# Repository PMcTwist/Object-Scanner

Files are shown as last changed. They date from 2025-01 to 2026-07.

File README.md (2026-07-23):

# Object Scanner

A low-cost, real-time 3D scanning platform built using **Python**, **C++**, **Arduino**, **Raspberry Pi**, and **LiDAR** technology.

Originally developed as a capstone project at the **University of Windsor**, Object Scanner was designed to demonstrate that accurate 3D scanning can be achieved using affordable, readily available hardware while providing a modular platform for future development and experimentation.

---

## Project Overview

Commercial 3D scanners are often prohibitively expensive for students, hobbyists, and small organizations. Object Scanner was created to provide an affordable alternative capable of producing real-time point cloud visualizations using open-source software and off-the-shelf hardware.

The system combines embedded firmware, desktop software, and custom hardware into a complete scanning platform capable of:

- Capturing real-time LiDAR/IR measurements
- Controlling dual-axis motion using stepper motors
- Processing scan data on a Raspberry Pi
- Visualizing point cloud data in real time
- Exporting captured scan information for future processing

---

## Features

- Real-time 3D point cloud visualization
- Python desktop application using PyQt5
- Arduino-based motion controller
- Raspberry Pi deployment
- SQLite scan data storage
- Live serial communication between hardware and software
- Configurable scan parameters
- Exportable scan data
- Modular architecture for future sensor upgrades

---

# Technologies

## Software

- Python
- PyQt5
- SQLite
- Matplotlib
- PySerial

## Embedded

- Arduino
- C++
- Stepper Motor Control
- Serial Communication

## Hardware

- Raspberry Pi
- TF-Luna LiDAR / IR Sensor
- NEMA Stepper Motors
- CNC Shield
- A4988 Drivers

---

# System Architecture

```
               +----------------------+
               |    Python GUI        |
               |      (PyQt5)         |
               +----------+-----------+
                          |
                    Serial Connection
                          |
               +----------v-----------+
               |      Arduino         |
               | Motion Controller    |
               +----------+-----------+
                          |
          +---------------+----------------+
          |                                |
   Stepper Motors                    LiDAR / IR Seonsor
          |                                |
          +---------------+----------------+
                          |
                    Scan Coordinates
                          |
               +----------v-----------+
               |    SQLite Database   |
               +----------+-----------+
                          |
               Real-Time 3D Visualization
```

---

# Screenshots

## User Interface

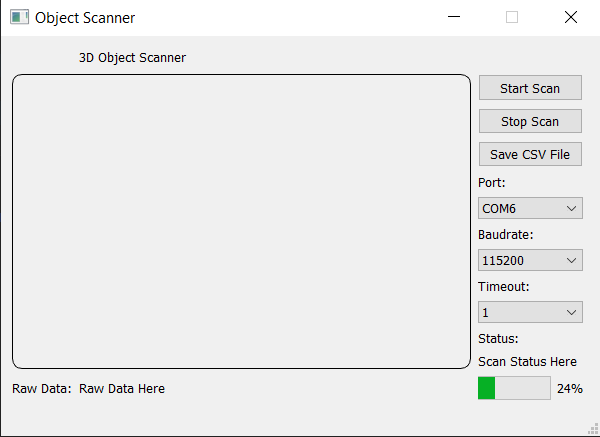
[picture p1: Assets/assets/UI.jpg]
Basic UI

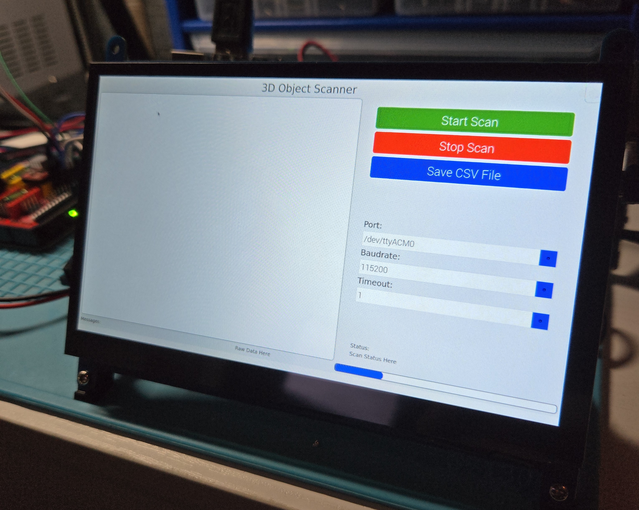
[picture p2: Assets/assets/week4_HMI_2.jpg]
UI Mock up


---

## Hardware

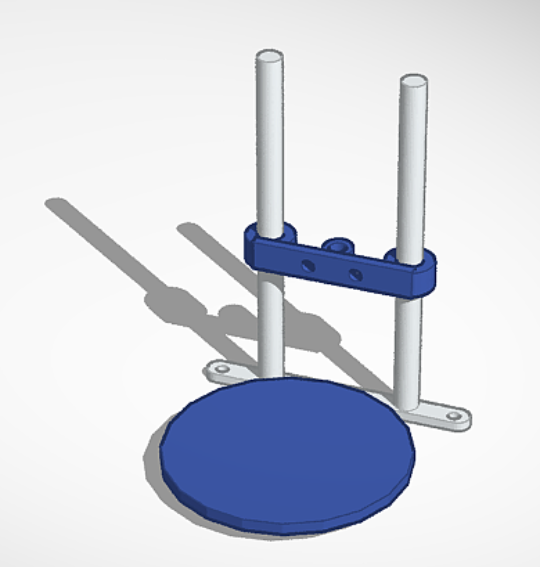
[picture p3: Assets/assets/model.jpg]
First CAD

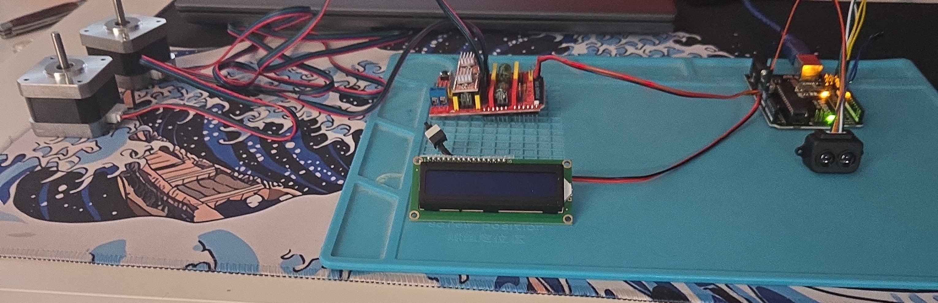
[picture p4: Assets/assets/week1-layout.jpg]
Basics

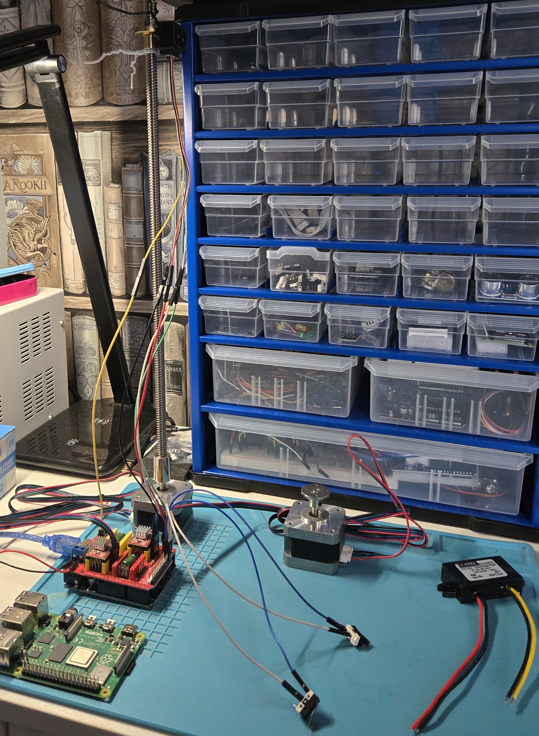
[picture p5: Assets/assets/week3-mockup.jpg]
Mechanical Mock up

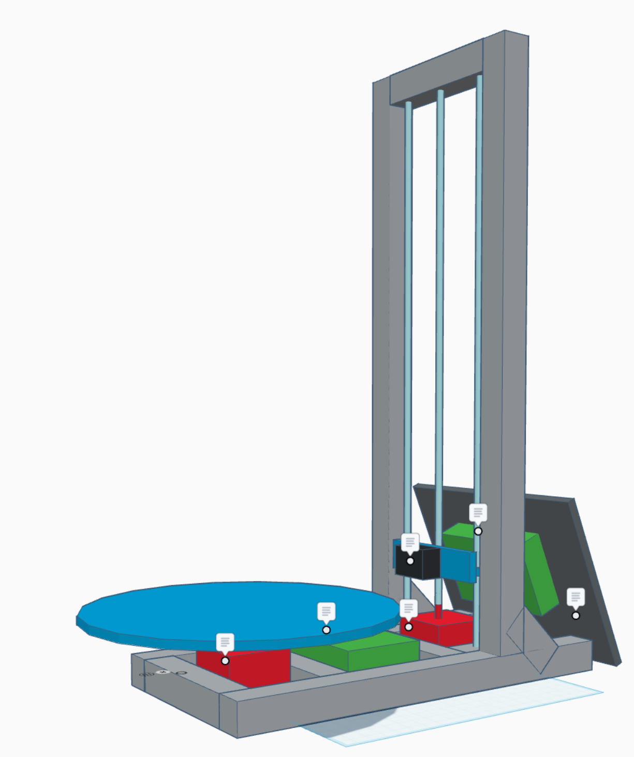
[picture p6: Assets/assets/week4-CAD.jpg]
CAD Update

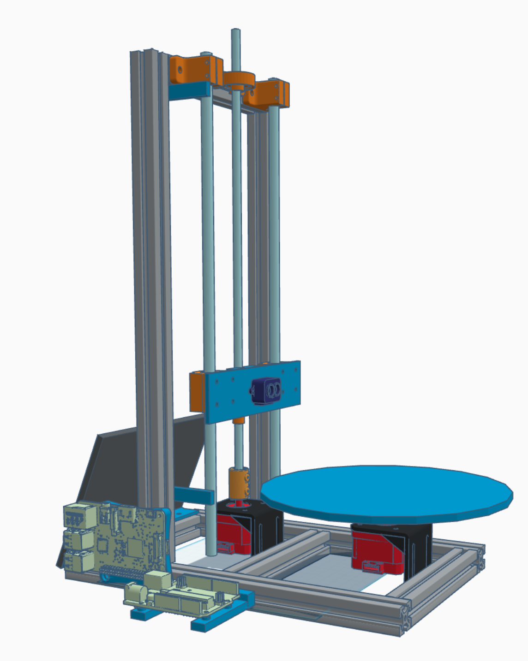
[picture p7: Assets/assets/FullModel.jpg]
Final Cad


---

## Run-Time

UI Update

---

# Repository Structure

```
Object-Scanner/

Arduino/
    Embedded firmware

Assets/
    Images and UI resources

Database/
    SQLite scan database

Models/
    3D printable components

Python/
    Desktop application

Releases/
    Executable releases

Scripts/
    Raspberry Pi startup scripts
```

---

# Installation

## Requirements

- Python 3.11+
- PyQt5
- Matplotlib
- PySerial
- SQLite3

Install dependencies:

```bash
pip install -r requirements.txt
```

---

# Running

Launch the application:

```bash
python scanner.py
```

Connect the Arduino via USB and configure the correct COM port before starting a scan.

---

# Future Improvements

Potential future enhancements include:

- Multi-threaded scan processing improvements
- Higher resolution scanning
- Additional sensor support
- Mesh generation
- STL export
- Network-based control
- Improved scan filtering algorithms

---

# Lessons Learned

This project provided valuable experience in:

- Embedded systems
- Python application development
- Hardware/software integration
- Real-time data visualization
- Multithreaded programming
- SQLite databases
- Raspberry Pi deployment
- Project planning
- Team collaboration

---

# Authors

## Patrick Maynard

Software Development  
Software Design • Embedded Systems • Automation

Email: patmaynard452@gmail.com
LinkedIn: https://www.linkedin.com/in/pat-maynard-b97a05b5/

---

## Kevin McClintock

Mechanical Design • Embedded Systems • Automation

Email:
LinkedIn:

---

# License

This project is released under the MIT License.

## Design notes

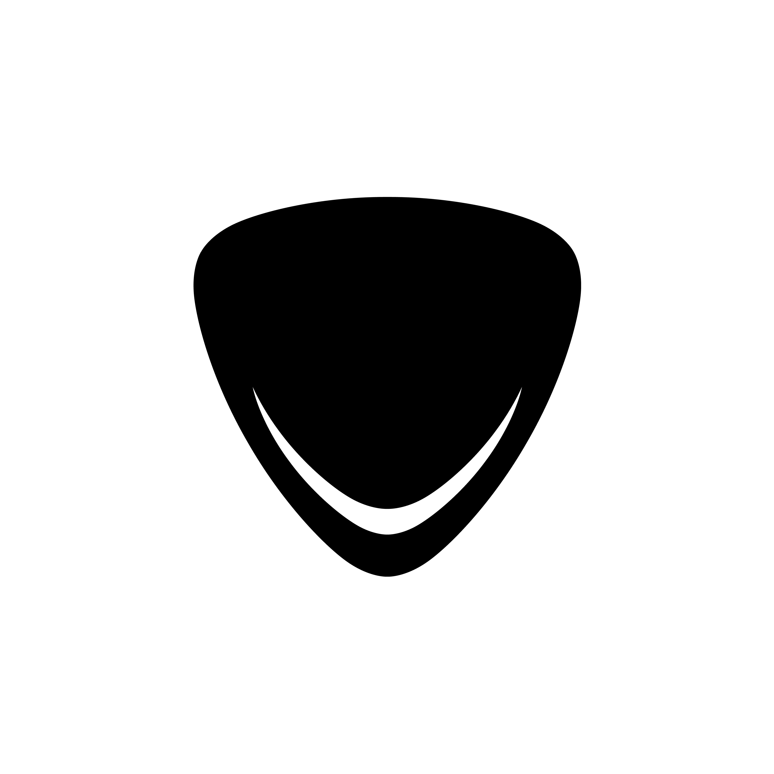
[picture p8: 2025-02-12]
Assets/arrow.png

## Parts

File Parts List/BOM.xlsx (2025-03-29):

Item | Cost | Link
CNC Driver Iinterface | 95 | RATTMMOTOR 3D Printer CNC Controller Kit Compatible with Arduino IDE, Nema17 Stepper Motor+UNO R3 Improvement Borad+CNC GRBL Shield Board V3 Expansion Board+DRV8825 Drivers+Mechanical Switches : Amazon.ca: Industrial & Scientific (https://www.amazon.ca/RATTMMOTOR-Controller-Compatible-Improvement-Mechanical/dp/B08KXL4GH7)
MERQC A4988 Driver
NEMA17 Motors
Arduino UNO
Motor Mounts
T8 8mm Threaded Rod | 17.9 | Richer-R 3D Printer Screw Rod, T8 8mm Trapezoidal Stainless Steel Threaded Rod Lead Screw & Brass Nut Easy to Install and Convenient to Use, No Need to Process for 3D Printer(100mm) : Amazon.ca: Industrial & Scientific (https://www.amazon.ca/Richer-R-Trapezoidal-Stainless-Threaded-Convenient/dp/B07CM3XTLX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)
8mm Guide Bearings | 11.99 | Eowpower 4 Pieces 8 mm Bore Diameter Ball Mounted Pillow Block Insert Bearings : Amazon.ca: Industrial & Scientific (https://www.amazon.ca/Eowpower-Diameter-Mounted-Pillow-Bearing/dp/B01MT1MODX)
8mmx400mm Guide Rods | 13.99 | Linear Motion Rods 2PCS 8mmx 250mm (0.315 x 9.84inches) Case Hardened Chrome Plated Linear Motion Rod Shaft Guide for 3D Printer, DIY, CNC - Metric h8 Tolerance : Amazon.ca: Industrial & Scientific (https://www.amazon.ca/Linear-Motion-9-84inches-Hardened-Printer/dp/B08JGD9F5P)
5mm Bore Flange Coupling | 13.99 | 4Pcs 8mm Flange Coupling Connector, Rigid Guide Model Coupler Accessory, Shaft Axis Fittings for DIY RC Model Motors : Amazon.ca: Tools & Home Improvement (https://www.amazon.ca/Coupling-Connector-Coupler-Accessory-Fittings/dp/B08334MFVT)
Threaded Rod Coupler | 16.49 | https://www.amazon.ca/uxcell-Coupling-Stainless-Connector-Accessories/dp/B07P82D36N
Power Adapter | 20 | Facmogu 3 Prong 12V 5A 60W AC to DC Power Supply Adapter with 9.84ft / 3m LONG CABLE, 5.5x2.1mm & 2.5mm Plug, AC 100-240V to DC 12V Switching Transformer Converter for CCTV Camera LED Strip LCD Screen : Amazon.ca: Electronics (https://www.amazon.ca/dp/B09BQBWKKT?ref=ppx_yo2ov_dt_b_fed_asin_title&th=1)
12V to 5V step down | 10.05 | https://www.amazon.ca/GAVIK-Waterproof-Buck-Converter-Intelligent/dp/B0CN455Z84
RaspBerry PI 4 | 101 | https://www.bestbuy.ca/en-ca/product/raspberry-pi-4-model-b-2019-quad-core-64-bit-wifi-bluetooth/15322892
RaspPi 7" HMI Screen | 55.36 | 7 Inch LCD Touch Screen, 1024x600 IPS Display with Stand, HDMI Portable Monitor for Raspberry Pi 5/4B/3B+/3B/B+/Zero/400, BB Black, Windows 10 8 7, Free Driver : Amazon.ca: Electronics (https://www.amazon.ca/1024x600-Display-Portable-Monitor-Raspberry/dp/B0CRRB1GFN)
Frame Extrusion | 60 | SeekLiny 10PCS T Slot 2020 Aluminum Extrusion European Standard 250mm(9.8’’) Length Anodized Extruded Aluminum for CNC DIY 3D Printer and Industrial Bracket Making, Ropes - Amazon Canada (https://www.amazon.ca/SeekLiny-Aluminum-Extrusion-European-Industrial/dp/B0CN6MFYJJ)
TF-Luna LiDAR Sensor | 36.59 | Wishiot TF-Luna LiDAR Range Finder Sensor 0.2m-8m Single-Point Ranging Module UART/I2C 5V with 6Pin Terminal to Dupont Cable for Arduino/RPi Pico/Pixhawk/WiFi_Lora_32 : Amazon.ca: Electronics (https://www.amazon.ca/Wishiot-TF-Luna-Single-Point-Terminal-WiFi_Lora_32/dp/B09PZ559ZB)
Total: | 452.36
*Note Frame can be 3D Printed from Included STL files

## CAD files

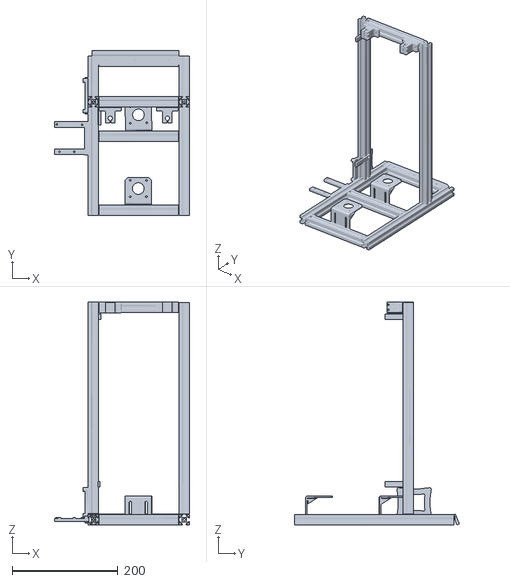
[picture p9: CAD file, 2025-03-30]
Models/PrintedParts/Full-Frame.stl
255.6 x 312.1 x 422.0

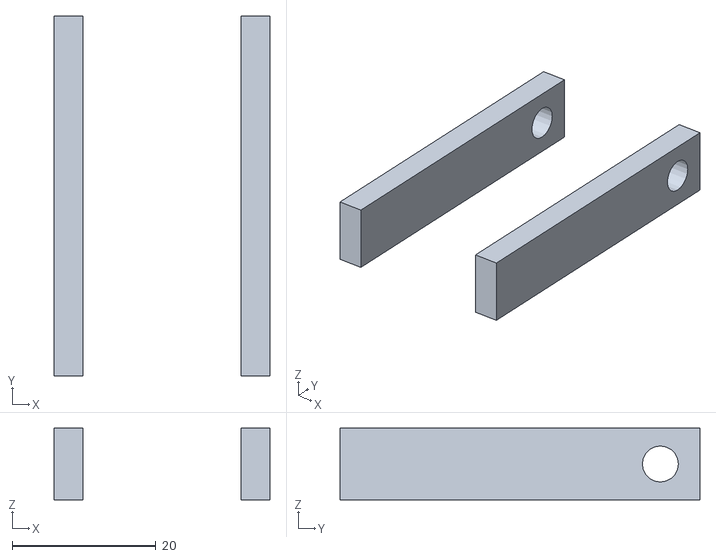
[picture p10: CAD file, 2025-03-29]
Models/PrintedParts/limit_mounts.stl
30.0 x 50.0 x 10.0

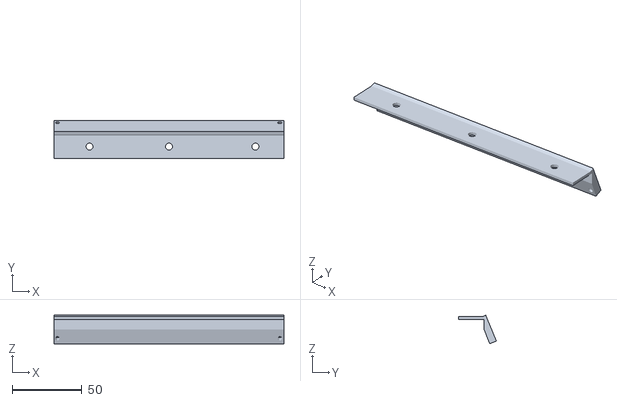
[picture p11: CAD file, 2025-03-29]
Models/PrintedParts/Screen Mount.stl
165.0 x 27.1 x 20.5

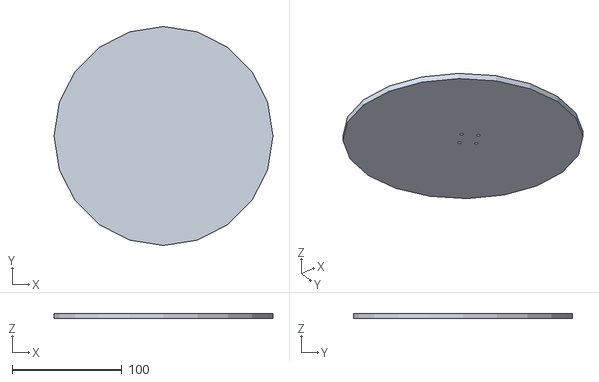
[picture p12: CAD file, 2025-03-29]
Models/PrintedParts/Platform.stl
200.0 x 200.0 x 5.00

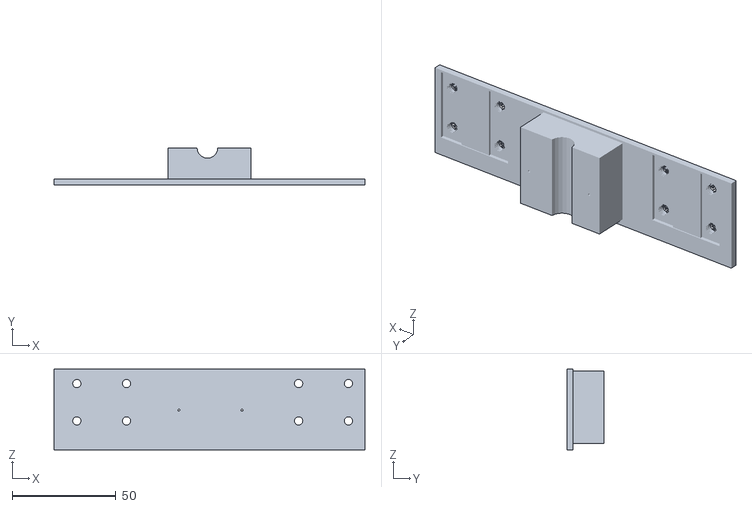
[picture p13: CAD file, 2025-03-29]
Models/PrintedParts/Sensor-Plate.stl
150.0 x 18.0 x 39.0

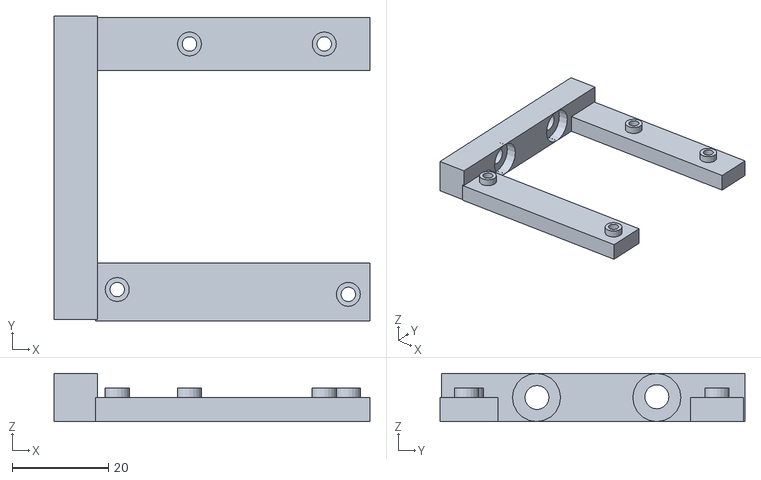
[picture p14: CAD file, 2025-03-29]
Models/PrintedParts/uno_Mount.stl
65.6 x 63.3 x 10.0

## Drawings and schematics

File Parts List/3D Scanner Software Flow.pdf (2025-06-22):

# Python HMI - Raspberry Pi or USB PC

# 3D Scanner Program Flow Diagram

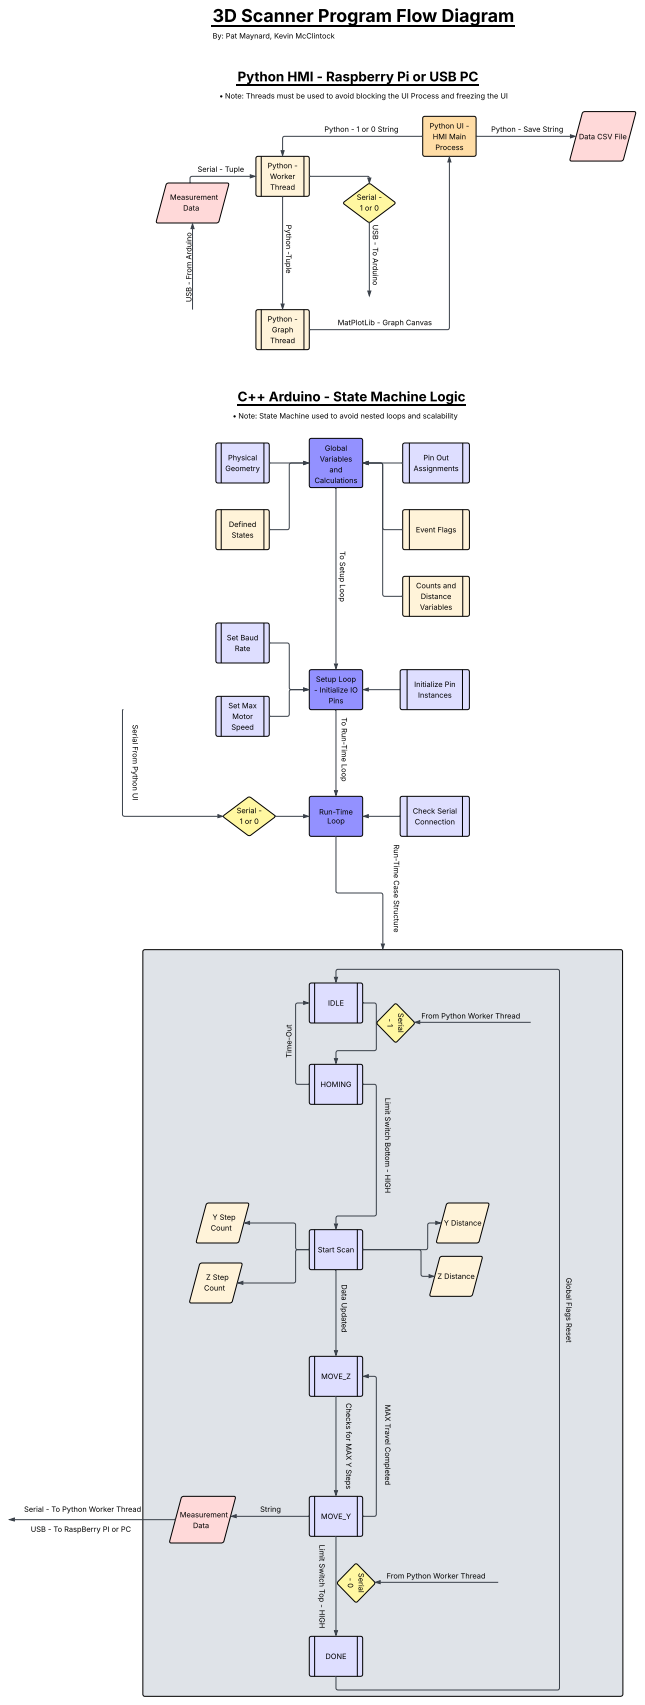
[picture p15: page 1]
Python UI - HMI Main Process; Python - Worker; Thread; Python - Graph Thread; Measurement Data; Serial - Tuple; Python - 1or 0 String; Serial - 1or 0; Global Variables and Calculations; Setup Loop - Initialize IO Pins; Physical Geometry; Pin Out Assignments; Defined States; Event Flags; Counts and Distance Variables; Check Serial Connection; Set Baud Rate; Initialize Pin Instances; Set Max Motor Speed; Run-Time Loop; IDLE; HOMING; Tim; e-Out; Start Scan; Y Step Count; Z Step Count; Y Distance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

By: Pat Maynard, Kevin McClintock

- Note: Threads must be used to avoid blocking the UI Process and freezing the UI

Python - Save String

Data CSV File

MatPlotLib - Graph Canvas

C++ Arduino - State Machine Logic

- Note: State Machine used to avoid nested loops and scalability

From Python Worker Thread

Serial - To Python Worker Thread

USB - To RaspBerry PI or PC

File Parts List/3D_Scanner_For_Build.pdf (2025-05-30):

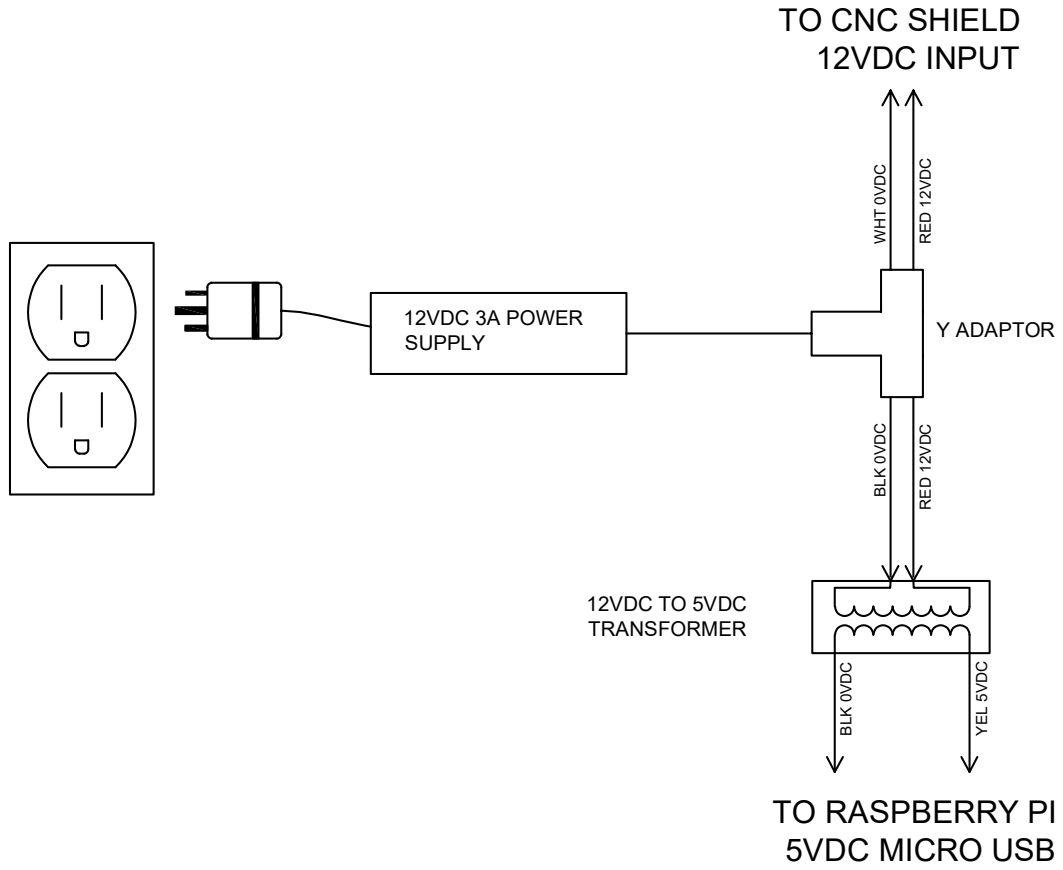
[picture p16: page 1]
12VDC 3A POWER; SUPPLY; Y ADAPTOR; 5VDC MICRO USB WHT 0VDC; RED ¹²VDC BLK ⁰VDC; YEL 5VDC; 12VDC TO 5VDC TRANSFORMER

TO CNC SHIELD
12VDC INPUT

TO RASPBERRY PI

# LIDAR SENSOR

# TF-LUNA

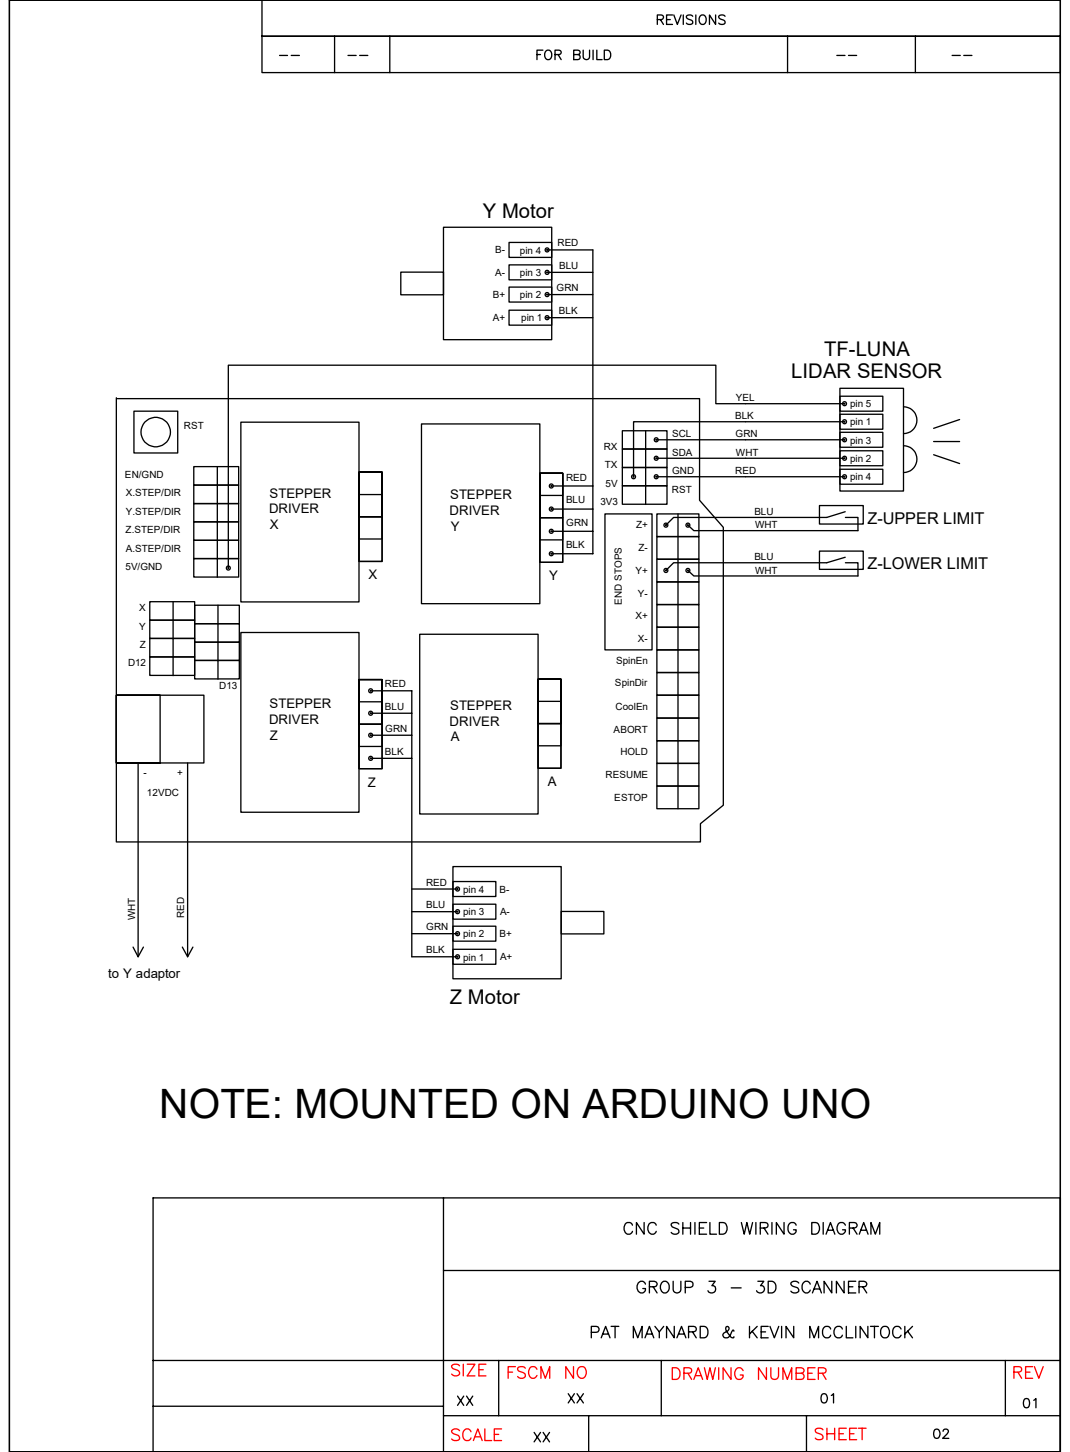
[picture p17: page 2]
X.STEP/DIR; Y.STEP/DIR; Z.STEP/DIR; A.STEP/DIR; 5V/GND; EN/GND; 12VDC; SCL RX; SDA GND; RST; Z+Z- Y+Y- X+X- SpinEn; RESUME; STEPPER DRIVER X; STEPPER DRIVER Z; STEPPER DRIVER Y; STEPPER DRIVER A; to Y adaptor; Z Motor WHT; RED; Z-UPPER LIMIT; Z-LOWER LIMIT; pin 5; pin 1; pin 3; pin 2; pin 4; BLU GRN; BLK; Y Motor RED; pin 3 B-; pin 4 A- B+A+

YELBLU WHT BLU WHT
BLK GRN WHT RED

ESTOP END STOPS X

SpinDir CoolEn ABORT HOLD

NOTE: MOUNTED ON ARDUINO UNO

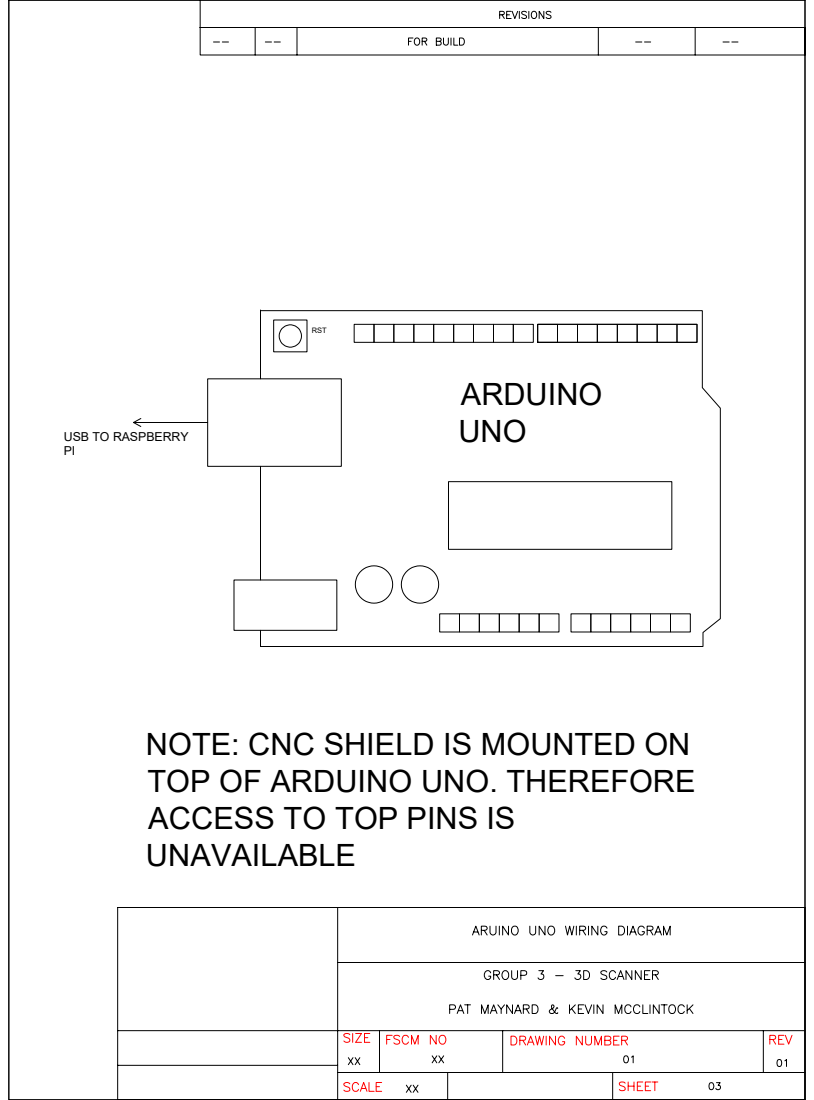
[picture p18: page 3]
RST; ARDUINO; UNO

USB TO RASPBERRY

NOTE: CNC SHIELD IS MOUNTED ON
TOP OF ARDUINO UNO. THEREFORE
ACCESS TO TOP PINS IS
UNAVAILABLE

# 7" HMI HDMI CABLE

# USB CABLE (TOUCH AND POWER)

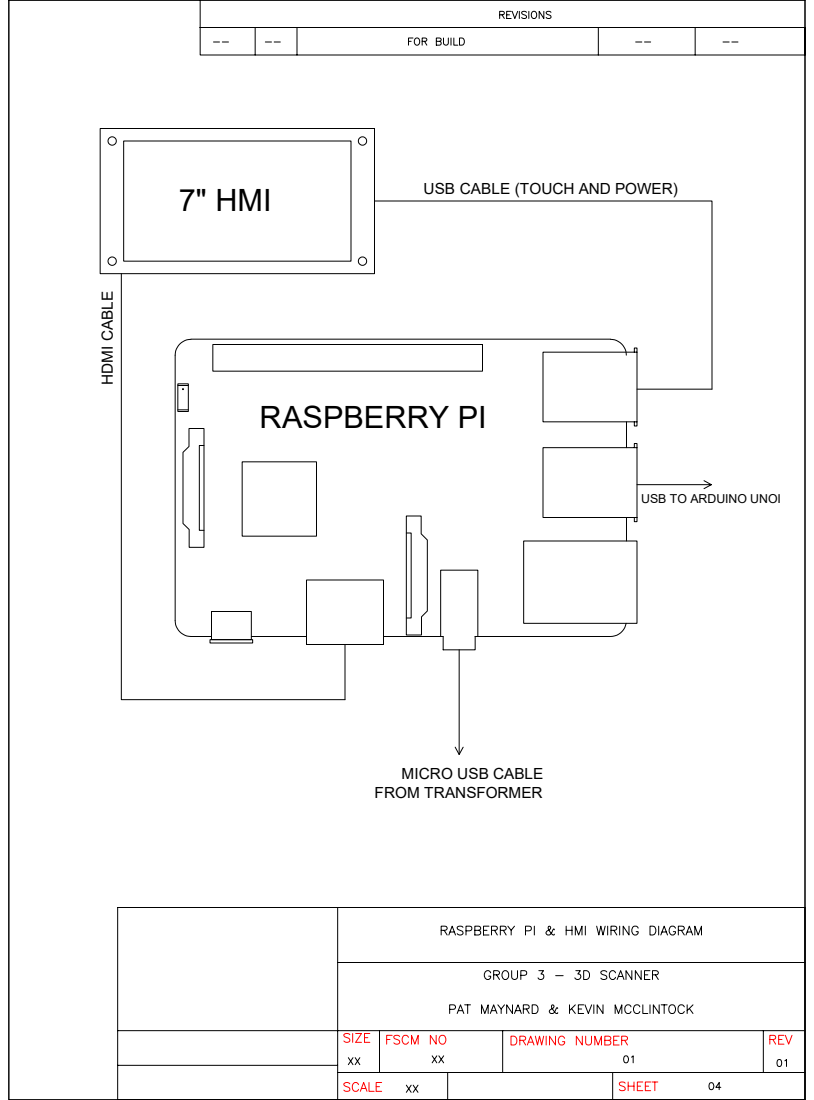
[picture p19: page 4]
RASPBERRY PI

USB TO ARDUINO UNOI

MICRO USB CABLE
FROM TRANSFORMER

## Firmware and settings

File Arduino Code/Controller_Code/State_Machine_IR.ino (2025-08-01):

#include <Arduino.h>

// ===== Sharp IR Sensor =====
#define SENSOR_PIN A0
int scan_amount = 40;  // Number of readings to average

// distance of sensor from middle of platform
const float distance_to_center = 150.0; // mm - adjust this to your actual setup

// ==== Full Step Configuration =====
const int micro_jumper = 2; // 2 is for 1/2 microstepping

// ===== Scan Parameters =====
// Reduce the scans per step to help scan time
const int stepsPerReading = 1;  // Take a reading every single step - no more multiple steps!

// ===== Platform Geometry =====
const float y_StepAngle = 1.8; // degrees per full step
const int motor_steps_per_rev = 360 / y_StepAngle; // 200 for 1.8°
const int stepsPerRev = motor_steps_per_rev * micro_jumper; // 200 * 2 = 400 for 1/2 steps
const float platformRadius = 100; // mm
const float platformCircumference = 2.0 * 3.1415926535 * platformRadius;
const float y_DistancePerStep = platformCircumference / stepsPerRev;

// ===== Threaded Rod Geometry =====
const float rodPitch = 2; // mm
const float z_stepsPerRev = 200 * micro_jumper; // 200 steps/rev for NEMA 17
const float z_DistancePerStep = rodPitch / z_stepsPerRev;

// ===== Stepper Pins & Setup =====
#define ENABLE_PIN 8

#define Y_STEP_PIN 3
#define Y_DIR_PIN 6

#define Z_STEP_PIN 4
#define Z_DIR_PIN 7
 
#define limitSwitchTop 11
#define limitSwitchBot 10

// ===== Scan State Machine =====
enum ScanState {
  IDLE,
  HOMING,
  START_SCAN,
  MOVE_Z,
  MOVE_Y,
  RECORD_DATA,
  DONE
};
ScanState scanState = IDLE;

// ===== Motion & Scan Variables =====
// Status flags
bool homingComplete = false;
bool running = false;
bool stopFlag = true;
bool homingStarted = false;
bool foundValidPoint = false;

// data send timer
unsigned long lastDataSendTimer = 0;
const unsigned long dataSendInterval = 50; // Reduced from 100ms to 50ms

// Homing variables
unsigned long homingStartTime = 0;
const unsigned long homingTimeout = 1000000000;

// 3 measured distances
float x_dist = 0.0;
float y_axis_total_distance = 0.0;
float z_axis_total_distance = 0.0;

// Array of send data
float dataArray[3];

int yStepCount = 0;
int zStepCount = 0;

const int yStepsPerZ = stepsPerRev; 
const int zStepsTotal = 200 * micro_jumper;
 
// Step timing variables
unsigned long lastHomingStepTime = 0;
const unsigned long homingStepInterval = 800; // Reduced from 1000 to 800 microseconds
 
// Faster 1/2 microstepping reliable stepping functions
void stepY(int direction) {
  // Set direction and wait
  digitalWrite(Y_DIR_PIN, direction > 0 ? HIGH : LOW);
  delayMicroseconds(500); // Reduced from 2ms to 500µs
  
  // Create step pulse
  digitalWrite(Y_STEP_PIN, HIGH);
  delayMicroseconds(200); // Reduced from 300µs to 200µs
  digitalWrite(Y_STEP_PIN, LOW);
  
  // Delay between steps - significantly reduced for speed
  delay(50); // Reduced from 100ms to 50ms
}
 
void stepZ(int direction) {
  digitalWrite(Z_DIR_PIN, direction > 0 ? HIGH : LOW);
  delayMicroseconds(300); // Reduced from 500µs
  digitalWrite(Z_STEP_PIN, HIGH);
  delayMicroseconds(80); // Reduced from 100µs
  digitalWrite(Z_STEP_PIN, LOW);
  delay(3); // Reduced from 5ms to 3ms
}
 
void stepZHoming() {
  // Non-blocking homing step
  if (micros() - lastHomingStepTime >= homingStepInterval) {
    digitalWrite(Z_DIR_PIN, LOW); // Move down for homing
    digitalWrite(Z_STEP_PIN, HIGH);
    delayMicroseconds(10);
    digitalWrite(Z_STEP_PIN, LOW);
    lastHomingStepTime = micros();
  }
}

// Sharp IR sensor reading function (returns distance in cm)
float readSensor(int samples = 40) {
  float analog_total = 0;
  float measured_analog = 0;

  for (int i = 0; i < samples; i++) {
    measured_analog = analogRead(SENSOR_PIN);
    analog_total += measured_analog;
    delay(2);  // Small delay between readings
  }

  float distance = analog_total / samples;  // Get the mean
  
  // Convert analog reading to voltage (assuming 5V reference)
  distance = (distance * 5.0) / 1023.0;
  
  // Sharp GP2Y0A51SK0F formula from datasheet (distance in cm)
  distance = -5.40274*pow(distance,3) + 28.4823*pow(distance,2) - 49.7115*distance + 31.3444;
  
  return distance;  // Return distance in cm
}

// Helper function for float mapping
float mapFloat(float fval, float val_in_min, float val_in_max, float val_out_min, float val_out_max) {
  return (fval - val_in_min) * (val_out_max - val_out_min) / (val_in_max - val_in_min) + val_out_min;
}
 
// Setup loop to define parameters
void setup() {
  Serial.begin(115200);
  
  pinMode(SENSOR_PIN, INPUT);
  analogReference(DEFAULT);  // Use 5V reference for Sharp sensor
  
  pinMode(ENABLE_PIN, OUTPUT);
  digitalWrite(ENABLE_PIN, HIGH); // Enable steppers
  
  pinMode(Y_STEP_PIN, OUTPUT);
  pinMode(Y_DIR_PIN, OUTPUT);
  
  pinMode(Z_STEP_PIN, OUTPUT);
  pinMode(Z_DIR_PIN, OUTPUT);
 
  pinMode(limitSwitchBot, INPUT_PULLUP);
  pinMode(limitSwitchTop, INPUT_PULLUP);
  
  Serial.println("STAT(Ready with Sharp IR sensor!)");
}

// ===== Main Loop =====
// This loop runs the state machine for the scanning process
void loop() {
  // Event Listener for UI
  if (Serial.available() > 0) {
    char inputChar = Serial.read() & 0x7F;
    Serial.print("Received: ");
    Serial.println(inputChar);
   
    if (inputChar == '1') {
      if (!running) {
        Serial.println("STAT(Starting Scan)");
        scanState = HOMING;
        running = true;
        stopFlag = false;
      }
    } else if (inputChar == '0') {
      if (running) {
        Serial.println("STAT(Stopping Scan)");
        scanState = DONE;
      }
    }
  }
  
  // State Machine Case Structure
  switch (scanState) {
    // Wait for instructions
    case IDLE:
      break;
    
    // Homes the Z axis to the 0 point to start
    case HOMING:
      digitalWrite(ENABLE_PIN, LOW); // Enable steppers for homing
      if (!homingStarted) {
        Serial.println("STAT(Homing Z Axis...)");
        homingStartTime = millis();
        homingStarted = true;
        lastHomingStepTime = 0;
      }
      // Check if limit switch is still open (not triggered)
      if (digitalRead(limitSwitchBot) == HIGH) {
        // Take homing steps
        stepZHoming();
        // Check for timeout
        if (millis() - homingStartTime > homingTimeout) {
          Serial.println("STAT(Homing timeout: switch not triggered.)");
          homingComplete = false;
          running = false;
          stopFlag = true;
          homingStarted = false;
          scanState = IDLE;
        }
      } else {
        // Limit switch triggered - homing complete
        Serial.println("STAT(Z axis homed successfully.)");
        homingComplete = true;
        homingStarted = false;
        scanState = START_SCAN;
      }
      break;
    
    // Initialize scan parameters
    case START_SCAN:
      Serial.println("STAT(Scanning...)");
      yStepCount = 0;
      zStepCount = 0;
      y_axis_total_distance = 0;
      z_axis_total_distance = 0;
      scanState = MOVE_Y;
      break;

    // Move Y motor for platform rotation and take measurements
    case MOVE_Y:
      if (yStepCount < yStepsPerZ) {
        Serial.println("STAT(Scanning...)");

        // Calculate current angle BEFORE taking measurement (this is the current position)
        float angle = (yStepCount * 2.0 * PI) / stepsPerRev;

        // reset point flag
        foundValidPoint = false;

        // Take averaged Sharp IR measurement (in cm)
        x_dist = readSensor(40);

        // Convert distance to mm and apply the working formula from reference code
        float measured_distance_mm = x_dist * 10; // Convert cm to mm
        float distance_from_center = distance_to_center - measured_distance_mm;

        // Check if the measurement is valid (object is between sensor and center)
        if (distance_from_center > 0 && distance_from_center <= (platformRadius * 2)) {
          // Scanned point is valid
          foundValidPoint = true;

          // Calculate Cartesian coordinates using the working formula
          float x = sin(angle) * distance_from_center;  // Note: sin for X
          float y = cos(angle) * distance_from_center;  // Note: cos for Y
          float z = z_axis_total_distance;

          // Prepare data
          dataArray[0] = x;
          dataArray[1] = y;
          dataArray[2] = z;

          // Send data with throttled timing applied (now faster)
          if (millis() - lastDataSendTimer >= dataSendInterval) {
            String dataToSend = String("DATA(") + String(dataArray[0]) + "," + String(dataArray[1]) + "," + String(dataArray[2]) + String(")");
            Serial.println(dataToSend);
            lastDataSendTimer = millis();
          }
        }

        // NOW move to next position AFTER taking the measurement
        for (int i = 0; i < stepsPerReading; i++) {
            stepY(1);
            y_axis_total_distance += y_DistancePerStep;
            yStepCount++;
            
            // Check if we've reached the total steps
            if (yStepCount >= yStepsPerZ) {
                break;
            }
        }
        
        // Faster delay between measurements
        delay(100); // Reduced from 200ms to 100ms
      } else {
        // Completed all Y steps for this Z level
        if (!foundValidPoint) {
          // Completed entire scan
          scanState = DONE;
        } else {
          // Move to next Z level
          scanState = MOVE_Z;
        }
      }
      break;
    
    // Move Z axis up for 0.5mm increments
    case MOVE_Z:
      Serial.println("STAT(Moving Z axis up - step ");
      Serial.println(zStepCount + 1);

      // Move Z up for 0.5mm increment
      // With 2mm pitch rod and 400 steps/rev (1/2 microstepping), each step = 0.005mm
      // For 0.5mm movement, use 100 steps
      for (int i = 0; i < 100; i++) {
        stepZ(1); // Move Z one microstep
      }

      // Z moved 0.5mm (100 steps * 0.005mm per step)
      z_axis_total_distance += 0.5; // 0.5mm per layer
      zStepCount++;

      // Reset Y parameters for this Z level
      yStepCount = 0;
      y_axis_total_distance = 0.0;
      scanState = MOVE_Y;
      break;
    
    // Complete state
    case DONE:
      if (digitalRead(limitSwitchTop) == LOW) {
        Serial.println("STAT(Top limit reached. Stopping scan.)");
      } else {
        Serial.println("STAT(Scan completed successfully.)");
      }
      homingComplete = false;
      running = false;
      stopFlag = true;
      scanState = IDLE;
      digitalWrite(ENABLE_PIN, HIGH); // disable steppers
      break;
  }
  // Small delay to prevent overwhelming the system
  delay(1);
}

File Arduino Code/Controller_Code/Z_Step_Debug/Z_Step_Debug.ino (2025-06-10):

// TEST 1

// #include <AccelStepper.h>

// #define Z_STEP_PIN 4
// #define Z_DIR_PIN 7
// #define ENABLE_PIN 8

// AccelStepper stepperZ(AccelStepper::DRIVER, Z_STEP_PIN, Z_DIR_PIN);

// void setup() {
//   Serial.begin(115200);
//   pinMode(ENABLE_PIN, OUTPUT);
//   digitalWrite(ENABLE_PIN, LOW);  // ENABLE motors

//   stepperZ.setMaxSpeed(400);
//   stepperZ.setAcceleration(100);
//   stepperZ.setSpeed(-200);  // Flip sign if needed
// }

// void loop() {
//   Serial.print("Trying to Step Z... ");
//   stepperZ.runSpeed();
// }

// TEST 2

// #include <Arduino.h>

// // ===== Stepper Pins =====
// #define ENABLE_PIN 8
// #define Y_STEP_PIN 3
// #define Y_DIR_PIN 6
// #define Z_STEP_PIN 4
// #define Z_DIR_PIN 7

// void setup() {
//   Serial.begin(115200);
//   // Set up pins
//   pinMode(ENABLE_PIN, OUTPUT);
//   pinMode(Y_STEP_PIN, OUTPUT);
//   pinMode(Y_DIR_PIN, OUTPUT);
//   pinMode(Z_STEP_PIN, OUTPUT);
//   pinMode(Z_DIR_PIN, OUTPUT);
//   // Enable the stepper drivers
//   digitalWrite(ENABLE_PIN, LOW);  // Try LOW first
//   Serial.println("Manual Stepper Test Starting...");
//   Serial.println("Testing Y motor first, then Z motor");
//   delay(2000); // Wait for driver to initialize
// }

// void loop() {
//   Serial.println("Testing Y Motor - 10 steps clockwise");
//   // Set direction
//   digitalWrite(Y_DIR_PIN, HIGH);
//   delay(100); // Let direction settle
//   // Take 10 slow steps
//   for(int i = 0; i < 10; i++) {
//     digitalWrite(Y_STEP_PIN, HIGH);
//     delay(100);  // Very slow for testing
//     digitalWrite(Y_STEP_PIN, LOW);
//     delay(100);
//     Serial.print("Y Step: ");
//     Serial.println(i + 1);
//   }
//   delay(2000); // Pause between tests
//   Serial.println("Testing Y Motor - 10 steps counterclockwise");
//   // Change direction
//   digitalWrite(Y_DIR_PIN, LOW);
//   delay(100);
//   // Take 10 slow steps
//   for(int i = 0; i < 10; i++) {
//     digitalWrite(Y_STEP_PIN, HIGH);
//     delay(100);
//     digitalWrite(Y_STEP_PIN, LOW);
//     delay(100);
//     Serial.print("Y Step: ");
//     Serial.println(i + 1);
//   }
//   delay(2000);
//   Serial.println("Testing Z Motor - 10 steps up");
//   // Set direction
//   digitalWrite(Z_DIR_PIN, HIGH);
//   delay(100);
//   // Take 10 slow steps
//   for(int i = 0; i < 10; i++) {
//     digitalWrite(Z_STEP_PIN, HIGH);
//     delay(100);
//     digitalWrite(Z_STEP_PIN, LOW);
//     delay(100);
//     Serial.print("Z Step: ");
//     Serial.println(i + 1);
//   }
//   delay(2000);
//   Serial.println("Testing Z Motor - 10 steps down");
//   // Change direction
//   digitalWrite(Z_DIR_PIN, LOW);
//   delay(100);
//   // Take 10 slow steps
//   for(int i = 0; i < 10; i++) {
//     digitalWrite(Z_STEP_PIN, HIGH);
//     delay(100);
//     digitalWrite(Z_STEP_PIN, LOW);
//     delay(100);
//     Serial.print("Z Step: ");
//     Serial.println(i + 1);
//   }
//   delay(5000); // Long pause before repeating
//   Serial.println("--- Test Complete - Repeating ---");
// }

// TEST 3

#include <Arduino.h>

// Define Z Axis pins (from original code)
#define ENABLE_PIN 8
#define Z_STEP_PIN 4
#define Z_DIR_PIN 7

void setup() {
  // Serial optional
  Serial.begin(115200);
  Serial.println("Z Axis Test Starting...");

  // Stepper driver setup
  pinMode(ENABLE_PIN, OUTPUT);
  digitalWrite(ENABLE_PIN, LOW);  // Enable stepper driver (Active LOW)

  pinMode(Z_STEP_PIN, OUTPUT);
  pinMode(Z_DIR_PIN, OUTPUT);

  // Set direction to "UP"
  digitalWrite(Z_DIR_PIN, HIGH);
}

void loop() {
  // Single step pulse
  digitalWrite(Z_STEP_PIN, HIGH);
  delay(1000);  // 10ms HIGH pulse
  digitalWrite(Z_STEP_PIN, LOW);
  delay(1000);  // 1 second delay between steps (slow visible stepping)

  Serial.println("Step Z");
}

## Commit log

2025-01-25 -Initialized project -Created gitignore and Venv -Created Boiler plate req txt
    P@
2025-01-25 -Removed USB and went straight to serial -Fucked up my drivers...need to fix before continuing
    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
    [scanner.py]
2025-01-26 -Set the default connection settings to match to what we have the arduino set to
    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
2025-01-26 - Updated the ui to load from a custom path - Added methods to handle button clicks - Added start and stop methods - Added combo box update methods - Slowly dreaded adding the realtime thread handler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
2025-01-26 - Fixed the button handler not being intialized...like a n00b
    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
    [scanner.py]
2025-02-02 - Started the setup of the worker thread instance and passing data to and from it for real time UI updates
    - Setup basic error handler for when I fail
    - Set enable and disable for start stop buttons depending on running state
    - Made read distance method to display last value read and append it to the save data array for later
    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
    [scanner.py]
2025-02-02 - Made worker class for threading
    - Setup up the pyqtSlot(used for signal passing) and the run method (Think of it as the void loop form arduino) for real time data handling
    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
2025-02-03 -Added proper stop method -fixed a bug with starting the port being already opened
    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
    [worker.py]
2025-02-03 -Updated the save file method to use a timestamp without : in it to stop a crash
    -Fixed a spelling mistake in a function name to get the measurment to actual happen... because I'm a dumbass
    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
    [scanner.py]
2025-02-03 -First sucessful saved real distance measurment file
    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
    [2025-02-02_19-57-32-scanData.csv]
2025-02-13 -Messed with the location of the instatiation of the worker instance and thread instance so it is an instance level variable usable by all methods in the class.
    -Changed a bit of the worker.stop method as well
    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
2025-02-16 - Added arduino code to the repo - Messing around with travel distance of the Y-axis measurements - Started setting up the Z travel distance code blocks
    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
2025-02-16 - Added the final data array - Updated the controller to send the 3 value row - Started to flesh out the Z axis measurement
    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
2025-02-17 - Commented out y-axis trials to let the other scripts run
    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
2025-02-17 - Had a hell of a time with real time system interrupts. Needed to be able to send a stop command while running nested loops. - Pulled the first part of the real-time loop out into a checkForUpdates 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
    [Capstone_trail_combined.ino]
2025-02-17 - Fixed issue with data filter - Fixed bug were graph dosent render because I saved it as a variable instead of updating the instance of the plot - Ran into issue were UI freezes because plot updates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
    [scanner.py]
2025-02-18 - Added new classes for other threads that need to run to keep the UI resonsive. - Moved the data validation to the grapher class - Moved the updateModel method to the grapher class
    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
2025-02-18 - Moved over methods to grapher class, just comments out for now. - Started to setup the threads for the grapher instance to run. - Updated the instance level comments in the class to clear up what I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
2025-02-18 removed place holder thread instances...not even sure why I still had them there to be honest..
    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
2025-02-19 - Changed the signal type to be a tuple - Moved the filter directly into the worker so it only emits tuples as signals - The worker will still emit errors to the status label if there is a problem - 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
    [scanner.py, worker.py]
2025-02-19 - Started working to get this class thread to work with data queue instead of a direct signal - Moved away from graphing each point. Now when there is a change in the Z data to will graph the last sl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
2025-02-19 -removed unneeded loader file. Should be able to update the progress bar from the worker or grapher threads
    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
2025-02-19 - Updated the grapher to be a QObject, typo when I made it a QThread. Now it can be called the same as worker by starting a thread and moving its own thread at run time. - Re-worked the run method to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
2025-02-19 - Updated the startScan to call the graph_thread to start and connect to grapher.run now that it is an object waiting to be started and not another thread. womp womp....
    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
2025-02-19 - added a method to update the progreess bar - Connected the slot to the the signal and attached it to the new method
    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
2025-02-19 - Started getting the data into a usable format -Broke out everything into print statements for debugging - Almost had everything working, the graph updated a few times and then stopped. Changed one 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
    [grapher.py]
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2025-03-29 -Added models for 3d printed parts
    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
    [Platform.stl, Screen Mount.stl, Sensor-Plate.stl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]
2025-03-29 -Added BOM to repo
    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
    [BOM.xlsx]
2025-03-30 -Added STL for a printable version of the frame
    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
    [Full-Frame.stl]
2025-05-26 - Added in the limit switches on pins 11 and 10 for the Z+ and Y+ of the CNC shield -Setup the home and top functions roughly, they need work - Debugged the Tx pin stopping the IDE from pushing the n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
    [Capstone_trail_combined.ino]
2025-05-28 -Updated the limit switch conditional to be while HIGH instead of LOW because it's NO and I had it backwards. -Troubleshot the Z stepper movement issue - it can move if forced but sounds like a buzz 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
    [Capstone_trail_combined.ino]
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2025-05-30 -Ran into an issue with AcclStepper having conflicts when run from a function call instead of the runtime loop() -Shoehorned existing code into a state machine setup to try to get around this issue..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
    [Capstone_trail_combined.ino, State_Machine.ino]
2025-05-30 -Removed all functions and function calls -Made every function into a part of the run-time loop and a case -Setup the check for update to become just an event listener at the start of the runtime loo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
    *Still having homing issues*
    [State_Machine.ino]
2025-05-30 -Tried some more homing logic to see if the AcclStepper library would play nice...it did not..
    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
2025-05-30 -Added serial print out to the stepping state of homing, we get there -Changed from runSpeed() to run() to test interval issues...runSpeed() was correct as per documentation
    https://www.airspayce.com/mikem/arduino/AccelStepper/classAccelStepper.html
    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
    [State_Machine.ino]
2025-06-03 -Messed with the state machine setup more. *Still unable to drive motor constaint for homing
2025-06-10 -Started to try different things to isolate our Z stepper issues -Commenting out older attempts incase something sparks joy and marie condo wouldn't want us to throw it out
    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
    [Z_Step_Debug.ino]
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2025-06-10 -Got the machine to move with this basic Z axis test code.
    *jumpers from step - dir pins on the CNC shield board were shorting and it was causing issues with the A4988 driver boards... *
    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
    [Z_Step_Debug.ino]
2025-06-10 -Updated time out to accomodate the slow moving of the Z axis motor *Will need to mechanically align the guide rods to fix slow movement and 'chainsaw' noise....*
    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
    [State_Machine.ino]
2025-06-12 - Updated the driver board to use microstepping at 1/4 to clean up the sound and janky movement - Updated code to have a micro step variable - Multiplied the end calcs for the platform rotation and r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
2025-06-12 - Updated data array and distance variables to float from int for better resolution
    * need to look at the TF Luna sensor library to see if I can increase the data resolution there too *
2025-06-14 - Messed around with the angular rotation calculations - Changed from R, Theta, z to x, y, z raw output over serial - Changed resolution for the Lidar by a factor of 10
    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
2025-06-14 - Moved clear canvas outside of the canvas plotting loop (fixed a huge bug!) - Removed references to the progress bar data and slot - Added a newData slot to stop the thread from forming a blocking l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
    P@ + Kevin
    [grapher.py]
2025-06-14 - Removed references and slots for the progress bar - Added a connection to the grapher new data slot
    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
2025-06-17 - Updated the calculation to take the new degrees per step into acount - using the platform radius to calc circumfrence now and using that to calculate the distance per step on the fly - Updated the 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
2025-06-17 - Changed the sin and cos for the x and y - Updated MOVE_Y to use the angle in calculation - Got the angle by multiplying the current step by 2 (because from the middle of the circle its two directio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
2025-06-22 - Changed Z travel from 2mm to 1mm - Updated the lidar to disregard negative numbers - Updated the Ldar to ignore scan points beyond the platfroms far edge
    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
2025-06-22 - Missed one status message
    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
    [State_Machine.ino]
2025-06-22 - Removed negative number filter...it's a 4 section plot...negatives are needed...
    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
2025-06-22 - Added a method to update the Status label if the encapsulated data is sent - Updated the error handler to update the serial label instead of the status label to keep them seperate
    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
    [scanner.py]
2025-06-22 - Decalired the foundVaildPoint flag globaly - Updated Move_Y to reset the flag to flase every pass until a valid point is found
    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
    [State_Machine.ino]
2025-06-22 - Updated the UI to emit a signal to stop the grapher instead of calling it's stop method directly - Stopping the worker by setting its running flag to flase instead ofcalling it's stop method direct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
2025-06-22 - Updated UI to also use pysignal to control the worker thread
    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
2025-06-22 - Broke out the stop, quit, wait calls into listener methods
    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
    [scanner.py]
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2025-07-01 - Moved the serial port session to the worker thread to avoid 'port already open' errors and freezing
    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
    [scanner.py]
2025-07-01 fixed flow issue for my sweet sweet OCD
    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
    [scanner.py]
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2025-07-01 - Removed unused Last Z variable from old method - Removed old math import - Removed instace setup for stopped signal - Added a check for AX and the grapher to be present before trying to graph...bec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
    [grapher.py]
2025-07-01 - Moved the 4 parts of the run method into their own methods to make it possible to keep track of the flow - Tried to make an arduino style setup/loop style for the worker thread. I think the while l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
    [worker.py]
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2025-07-01 - upped the delay from 0.5 sec to 2 sec when setting up the new serial port to the arduino. The port was resetting to fast - Added an emit on clean up to let the main process know the worker has stop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
    [worker.py]
2025-07-01 - Noticed the data loop was blocking any signals from processing. - Added in QApplication.processEvents() in the head of the loop. this fixed the freezing issue but now data dosent get collected....o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
    [worker.py]
2025-07-03 - Put a timer and check for sending data. Trying to avoid overwhelming the worker thread.
    I figured out that the data is hammering the data worker too fast and it's not catching system interupts sent from the ui to stop the data collection. Added 100ms delay between data scans in the firmware to avoid this on the arduino side.
    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
    [State_Machine.ino]
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2025-07-13 -After adding the delay, Readding the processEvent call fixed the UI locking up.
    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
    [worker.py]
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2025-07-17 - Thought more about the approach of taking 100 samples to average out the error of the sensor. Applied that mindset to the LiDar sensor code. - Put in a resolution throttle variable - Only takes sam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
    * Need to update UI to accomodate a dynamic throttle variable, and add a save file output path for the embedded UI *
    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
    [State_Machine.ino]
2025-07-17 -corrected function call name
    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
    [State_Machine.ino]
2025-07-18 Update State_Machine.ino
    - Added a sensor offset
    - Added offset to sensor reading calculations to avoid the object being rounded when scanned
    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
    [State_Machine.ino]
2025-07-19 - Updated save file to let user select save location - Added an if filename to stop it from crashing when user cancels the popup box - Started to integrate SQLite3 for saving data
    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
    [scanner.py]
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2025-07-19 -Fixed calling the db_path directly and called the instance variable that I setup isntead
    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
    [grapher.py]
2025-07-19 -Updated the grapher thread to send a signal on polling to then let the graph know to pull data from the database if the last index value is different than the previous one. This lets us not have to 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
    [grapher.py]
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2025-07-21 -Adjusted for a conversion error. I have 150 mm is 1.5 cm. It is now 15mm is 1.5 cm
    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
    [State_Machine.ino]
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
